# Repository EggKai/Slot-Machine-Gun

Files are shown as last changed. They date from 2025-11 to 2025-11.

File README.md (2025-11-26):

# Slot Machine Gun
This project serves as an allegory for the inherent risks of gambling, emphasizing how effortlessly individuals can descend a slippery slope of chance and compulsion through the personification and of these hazards in this playful, gamified form, combining a slot machine with a foam dart launcher and a face tracking gimbal.
Physical build

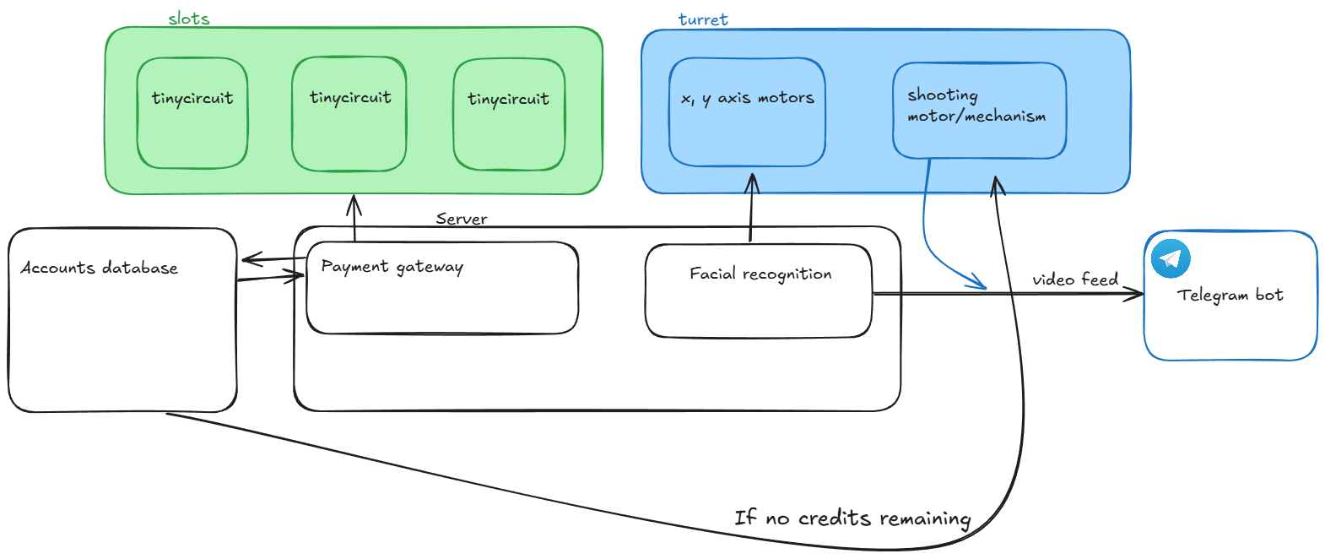
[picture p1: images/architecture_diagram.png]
System Architecture


## What's in the repo
- `slots/` - TinyScreen+ slot firmware (`jackpot_extra3x1.ino`) and MFRC522 RFID scan sketch (`rfid_scanner.ino`).
- `payment/gateway/` - Python bridge for RFID -> credit server and socket messaging to slots/turret.
- `payment/gateway/jackpot.py` - Slot "casino" server that drives the three slot displays and computes payouts.
- `payment/server/` - SQLite schema, forms, and stubs for the credit service that owns balances (plus Android NFC top-up client in `AppInterface/`).
- `turret/src/` - Arduino Uno firmware for three ULN2003/28BYJ-48 steppers (pan/tilt/fire) with a serial command set.
- `turret/host/` - Python tooling: serial CLI + OpenCV face tracking (`stepper_cli.py`) and Telegram clip sender (`killcambot.py`).
- `schematics/` and `images/` - Mechanical/electrical references, turret photos, and wiring diagrams.

## System design
- **Slots subsystem** - Three TinyScreen+ displays (clients 2, 3, 4) each with a WiFi TinyShield. They spin symbols and report results back to the jackpot server; they also render credit depletion and payout notices.
- **Payment gateway** - An MFRC522 RFID reader + Arduino serial output. A Python bridge charges spins against a credit service and forwards results to the jackpot server; it also notifies the turret when credits hit zero.
- **Credit service** - SQLite-backed HTTP API (expected to be served via `uvicorn main:app`). Holds RFID -> credit balances, admin UI, and Android NFC top-up app.
- **Turret** - Two-axis gear-driven rig plus a firing servo, controlled by Arduino firmware over serial. A host Python CLI performs face tracking and reacts to "NO CREDS" events via TCP.

### Key images
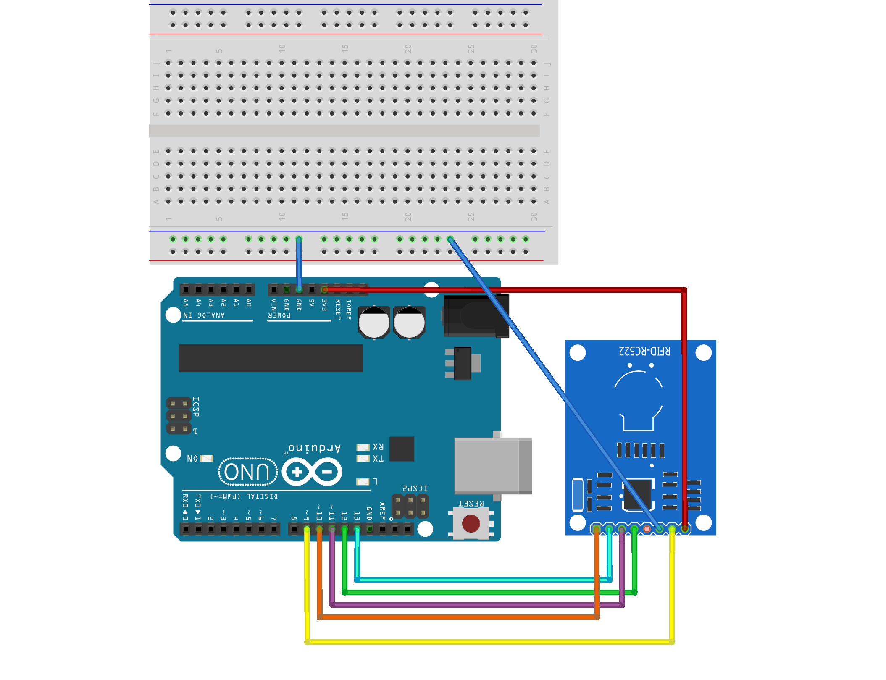
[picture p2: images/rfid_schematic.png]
RFID schematic
- Slots + payment wiring: 
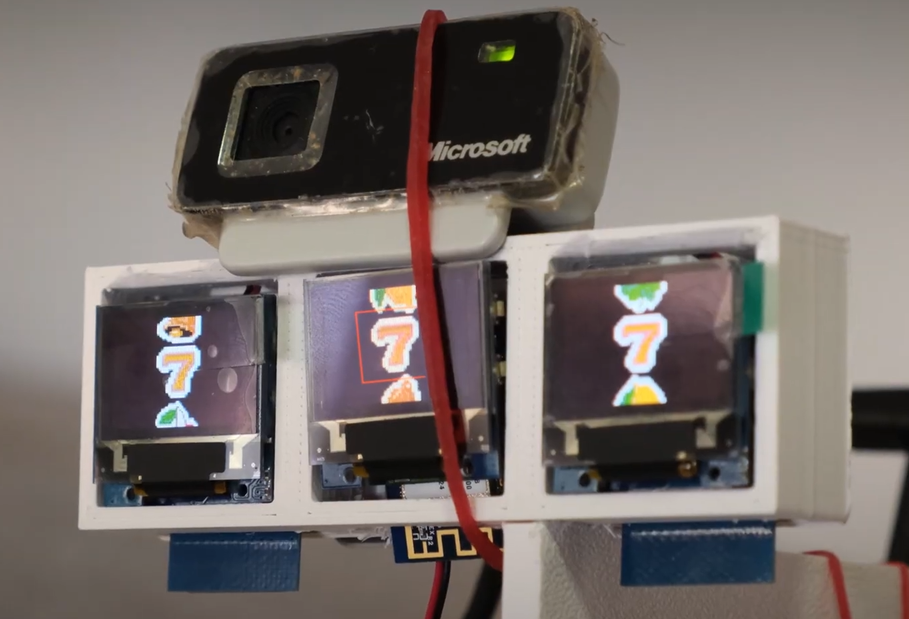
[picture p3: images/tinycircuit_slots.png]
TinyCircuits slots
- Slots UI: 
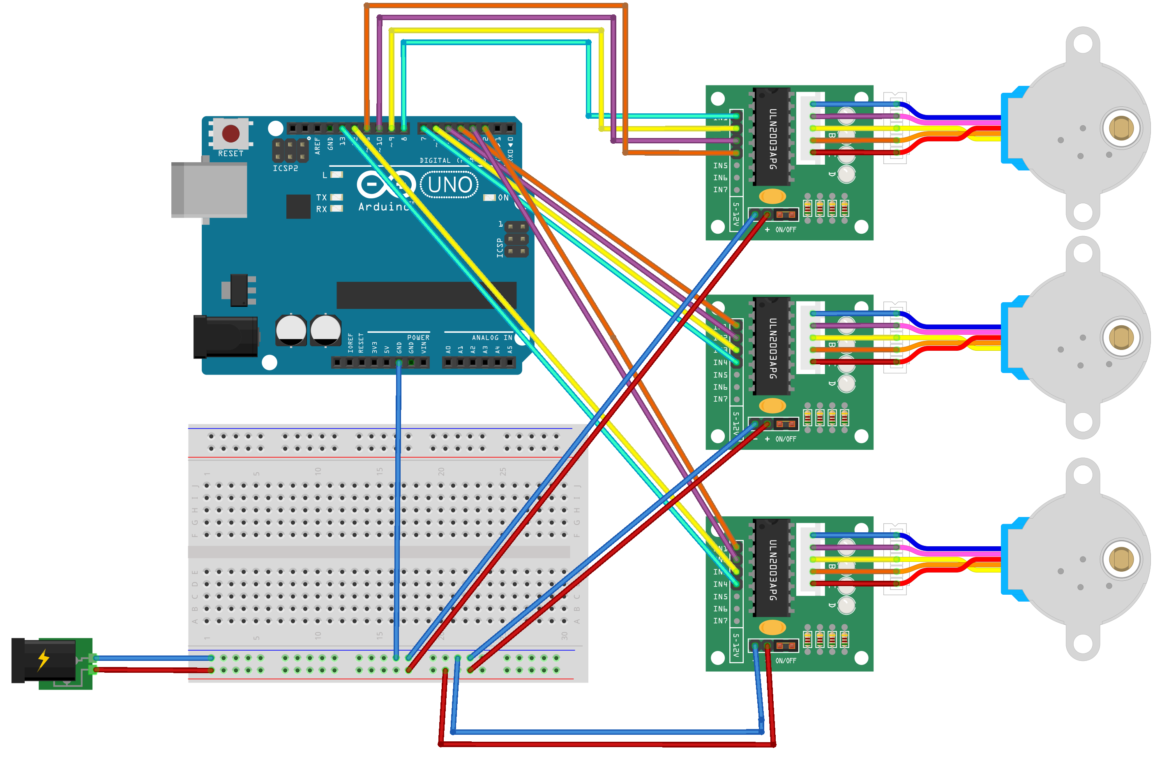
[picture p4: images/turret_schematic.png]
Turret schematic
- Turret wiring: 
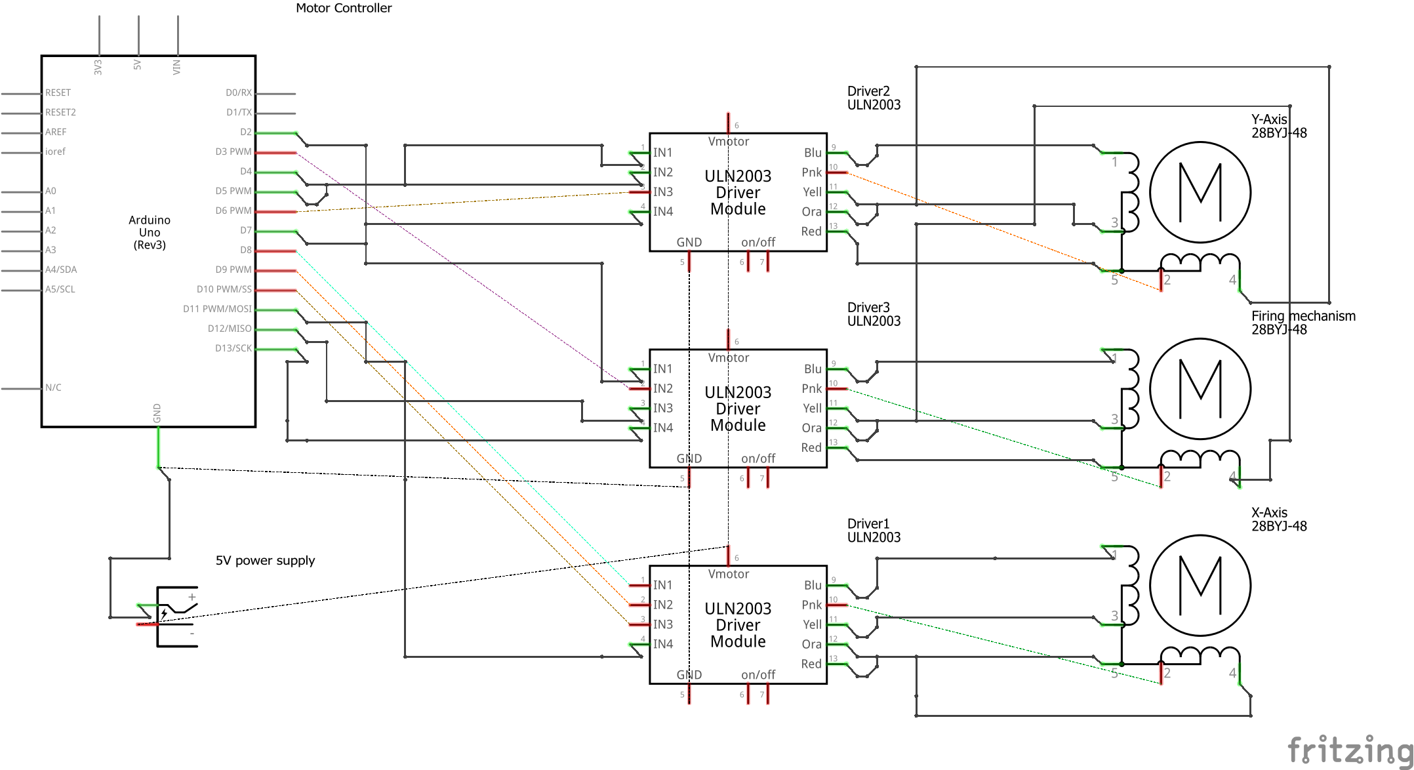
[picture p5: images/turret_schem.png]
Turret electrical wiring
- Turret wiring schema: 

## Parts lists
**Turret**

Components  
| Label | Part Type | mn | mpn | part number |
| --- | --- | --- | --- | --- |
| 5V power supply | Power plug |  |  |  |
| Driver1 | 28BYJ-48 Driver Module |  |  | ULN2003 |
| Driver2 | 28BYJ-48 Driver Module |  |  | ULN2003 |
| Driver3 | 28BYJ-48 Driver Module |  |  | ULN2003 |
| Firing mechanism | 28BYJ-48 Stepper Motor |  |  | 28BYJ-48 |
| Motor Controller | Arduino Uno (Rev3) |  |  |  |
| X-Axis | 28BYJ-48 Stepper Motor |  |  | 28BYJ-48 |
| Y-Axis | 28BYJ-48 Stepper Motor |  |  | 28BYJ-48 |

Quantities  
| Amount | Part Type | mn | mpn | part number |
| --- | --- | --- | --- | --- |
| 3 | 28BYJ-48 Driver Module |  |  | ULN2003 |
| 3 | 28BYJ-48 Stepper Motor |  |  | 28BYJ-48 |
| 1 | Arduino Uno (Rev3) |  |  |  |
| 1 | Power plug |  |  |  |

**Payment gateway**

Components  
| Label | Part Type | mn | mpn | part number |
| --- | --- | --- | --- | --- |
| Part1 | Arduino Uno (Rev3) |  |  |  |
| Part3 | RFID-RC522-v2 |  |  |  |

Quantities  
| Amount | Part Type | mn | mpn | part number |
| --- | --- | --- | --- | --- |
| 1 | Arduino Uno (Rev3) |  |  |  |
| 1 | RFID-RC522-v2 |  |  |  |

## Slots firmware (`slots/jackpot_extra3x1.ino`)
- Targets Arduino TinyScreen+ with WiFi TinyShield; draws three clipped symbol rows and performs weighted spins (`symbolOdds`).
- Networking: set `ssid`, `pass`, `serverIP`, and `port` (default `10.102.150.117:5000`). Each client sets a unique `devNum` (2, 3, or 4) and static IP (`localIp`).
- Protocol:
  - Client connects and sends `[0xFD, devNum]`. Server replies `0xFE` handshake; client answers `0xFF`.
  - A single byte `0-5` commands the middle symbol target; client streams 4 bytes back `[devNum, top, mid, bottom]`.
  - `0xAA` -> display "No Credits Left"; `0xAB` + payout byte -> show "You win N credits!".
  - High-bit masks (`0x80 | bits`) flash winning rows.
- Build/upload: use Arduino IDE with TinyScreen/WiFi101 libs, or PlatformIO if you port the board definition. Flash three devices with distinct `devNum`.
- For graphics, assets, and deeper slot behavior docs, see `slots/game_and_graphics_docs.pdf`.

## RFID scan sketch (`slots/rfid_scanner.ino`)
- MFRC522 wired to SS=D10, RST=D9; streams detected UID over serial to the Python gateway.
- Blocks further scans until it receives `DONE` (or `BAL:<float>`) over serial from the gateway.

## Jackpot server (`payment/gateway/jackpot.py`)
- Listens on `0.0.0.0:5000` for slot clients.
- Maintains credits, issues spin targets, collects results, computes payouts (`MULTIPLIERS`), and triggers row flashes.
- Commands:
  - Enter to roll random (deducts `BET`), `t N` to force all reels to symbol `N`.
  - `c` add 100 credits, `s` show credits, `set N` override balance, `q` quit.
- Also hosts a localhost-only channel for the RFID gateway: receives `"SUCCESS"` to roll and return a payout to the gateway, or `"NO CREDS"` to send `0xAA` to slots.

Run:
```bash
python payment/gateway/jackpot.py
```

## Payment gateway bridge (`payment/gateway/deduct_credits_to_spin.py`)
- Dependencies: `requests`, `pyserial`.
- Serial: listens to RFID UID lines from the Arduino on `SERIAL_PORT`/`BAUD_RATE`.
- HTTP: posts to credit API (`BASE_URL` deduct, `BASE_URL_2` add payout).
- Sockets:
  - Connects to jackpot server at `HOST:PORT` (default `127.0.0.1:5000`) to send `"SUCCESS"`/`"NO CREDS"` and read payout bytes.
  - Connects to turret listener at `HOST2:PORT2` (default `10.102.150.134:9000`) to forward `"NO CREDS"` so the turret can react.
- Serial flow: after each scan it sends `DONE` back to the Arduino to re-arm scanning.
- Update the hard-coded IPs/ports and amounts before running.

Run:
```bash
python payment/gateway/deduct_credits_to_spin.py
```

## Credit service (`payment/server`)
- SQLite schema in `database.py` with `users`, `rfid_cards`, and `customers`; DB file `shop.db`.
- Pydantic models in `models.py`; `.env` holds `DEDUCTION_AMOUNT`.
- Templates: login/register flows and `dashboard.html` for admin credit adjustments and customer listing.
- QA helper: `qa_test.py` posts a sample RFID deduct request to `http://127.0.0.1:8000/rfid/deduct`.
- Intended to run with `uvicorn main:app --reload --host <ip>` (see `start.txt`). Ensure `main.py` exposes a FastAPI/Starlette `app` and routes for:
  - `POST /rfid/deduct` and `POST /rfid/add` (used by the gateway bridge),
  - `POST /admin/add` (used by the Android NFC client),
  - auth + dashboard routes rendered from `templates/`.

> Note: the current `main.py` is a stub; wire up the FastAPI/Flask app to match the expected endpoints above.

## Android NFC top-up (`payment/server/AppInterface`)
- Simple NFC Activity (`MainActivity.kt`) reads a tag, displays the UID, and POSTs to `http://103.213.247.25:8000/admin/add` with `rfid_id` + `amount`.
- Built with Gradle/Kotlin (see `build.gradle.kts`); UI layout in `app/src/main/res/layout/activity_main.xml`.

## Turret firmware (`turret/src/main.cpp`)
- PlatformIO project for Arduino Uno driving three ULN2003/28BYJ-48 steppers (A: D8-D11, B: D4-D7, C: D2/D3/D12/D13) with direction inversion flags.
- Serial command set (115200 baud): `HELP`, `SPEED <rpm>`, `A|B|C <steps>`, `AB <a> <b>`, `ABC <a> <b> <c>`, `TARGET`, `STOP/RESUME`, `RELEASE`, `DEMO ON|OFF`.
- `TARGET` macro sweeps motor C; `DEMO` oscillates all axes for burn-in.
- Build/upload with PlatformIO:
```bash
cd turret
pio run -t upload
pio device monitor -b 115200
```

## Turret host tools (`turret/host`)
- `stepper_cli.py` - Serial client plus extras. With no arguments it now auto-runs face tracking + listener with: `track --port COM5 --cam 0 --cam-api dshow --rpm 12 --step-scale 0.05 --max-step 50 --listen-while-track (default on) --tcp-host 0.0.0.0 --tcp-port 9000`.
  - Basic commands: `python stepper_cli.py speed 15 --port COM5`.
  - Face tracking (custom): `python stepper_cli.py track --port COM5 --cam 0 --cam-api dshow --rpm 12 --step-scale 0.05 --max-step 50`.
  - TCP listener: `python stepper_cli.py listen --tcp-port 9000` to react to `"NO CREDS"` from the payment gateway (fires motor C sweep and optional camera clip).
  - Combined tracking + listener (custom ports/backends): `python stepper_cli.py track --listen-while-track (default on) --tcp-host 0.0.0.0 --tcp-port 9000`.
- `killcambot.py` - Utility to send recorded clips to Telegram subscribers; requires `python-telegram-bot` and a valid bot token/chat IDs.

## Suggested bring-up order
1. **Credit service** - Ensure `/rfid/deduct`, `/rfid/add`, and `/admin/add` endpoints work against `shop.db`.
2. **Jackpot server** - Start `payment/gateway/jackpot.py` and seed credits via the console (`c` or `set N`).
3. **Turret listener** - Run `stepper_cli.py listen --tcp-port 9000` (or `track --listen-while-track (default on)`).
4. **Gateway bridge** - Start `deduct_credits_to_spin.py` with correct serial port and API IPs.
5. **RFID scanner** - Flash `slots/rfid_scanner.ino` to the reader Arduino.
6. **Slot displays** - Flash `slots/jackpot_extra3x1.ino` to three TinyScreen+ units with `devNum` 2/3/4 and confirm they reach the server.

## Security & safety notes
- Secrets are currently in-source (WiFi SSID/password, Telegram bot token, service IPs). Rotate these for any real deployment.
- The build involves moving hardware (turret servos/steppers) and projectile firing-keep clearances, test without darts first, and add hard stops or current limits as needed.
- Gambling theme is illustrative only; do not deploy in environments with minors or where gambling content is restricted.

## Troubleshooting
- Slots not connecting: verify WiFi credentials, static IPs, and that `serverIP`/port are reachable; confirm the `0xFE/0xFF` handshake completes.
- No payouts: check jackpot console logs for missing device reports or insufficient credits; ensure `LINES` covers the row you expect.
- Gateway timeouts: confirm the credit API is reachable; inspect `BASE_URL`/`BASE_URL_2` and network paths.
- Turret not moving: check COM port, 5V supply to ULN2003 boards, and use `stepper_cli.py help` or `repl` to issue manual steps.

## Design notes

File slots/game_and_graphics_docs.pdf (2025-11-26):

# Gambling-Like Machine Using TinyCircuits and a Python Backend

Author: Tan Yehan

Date: 25/11/2025

## 1. Introduction

This report documents the design, implementation, and limitations of a gamblingmachine-like system constructed using three TinyCircuits boards (one TinyScreen+ and two TinyScreen units) equipped with WiFi TinyShields, acting as the slot-machine reels. The system communicates with a Python server that interprets results, enforces winning conditions, and issues commands back to the devices. Devices and Python server need to share the same Wifi AP.
The implementation served as part of a larger group project. This report covers only the components I directly developed and contributed, excluding architectural changes introduced later by teammates (e.g., DHCP support, credit display logic, or integration with an RFID-based credit and turret subsystem).

## 2. Hardware Overview

The system consists of:
- 3 TinyCircuits microcontroller units, each attached to
- one TinyScreen(+) display or TinyScreen(default) display,
- one WiFi TinyShield capable of basic TCP communication. Each device is programmed individually via the Arduino IDE using a dedicated .ino sketch.
All graphical assets (six slot icons) are stored as bitmaps:
- Bell
- Cherry
- Clover
- Diamond
- Lemon

- Seven
These are indexed 0–5 respectively on the microcontroller.

## 3. Software Architecture (Device Side)

## 3.1 Hardcoded Network Configuration

In the version I authored, each device contains:
- a hardcoded SSID and WiFi password,
- a fixed local IP address,
- the hardcoded IP address of the backend server.
This static addressing was required at the time because:
1. The device software must know the server IP before initiating the TCP handshake.
2. The backend required identifying devices by a predetermined “device number” (devNum).
3. Initially, each device’s identity was implicitly mapped to its IP address. Teammates later reworked this into a DHCP-compatible model. I do not document those changes here as they were not part of my contribution.

## 3.2 Device Identity (devNum)

Each TinyCircuit device sends a two-byte header upon connection:
[0xFD, devNum]
Only device numbers 2, 3, and 4 are valid.
These map to slot-machine columns 0, 1, and 2 respectively. Changes will need to be made for more device numbers and columns.

## 3.3 Local Odds and Symbol Selection

Each device maintains its own probability distribution for selecting the three row symbols during a spin. The odds I implemented were:

Symbol | Weight
Bell | 23

Symbol | Weight
Cherry | 23
Clover | 16

Diamond 16

Lemon | 13
Seven | 9

These weights apply only to the top and bottom rows after the design was scaled down (see Section 6).
The middle row is always assigned by the server, not by the device.

## 4. Server–Device Communication Protocol

## 4.1 Server Handshake and Heartbeat

After accepting a connection, the server expects:
Byte 0: 0xFD
Byte 1: devNum
If this header fails validation, the server drops the connection.
To check on the connection between device and server, the server periodically sends a handshake / keep-alive byte:
0xFE
If the client does not respond (e.g., due to crash or network loss), the server removes it from the active client list and waits for a new connection.

## 4.2 Commanding the Middle Row

To control the displayed result for the middle row, the server sends exactly one byte: 0–5 (index of symbol to display in middle row)
This allows the server to:
- randomly determine outcomes,

- enforce specific outcomes for testing or demonstration (e.g., guaranteed win/loss),
- synchronise the “middle row” across devices.
This design choice mimics real-world gambling systems where top/bottom rows often simulate randomness but have no effect on payout.

## 4.3 Device → Server Result Reporting

After each spin, the device sends four bytes:
[devNum, top, mid, bottom]
Each value is a symbol index (0–5).
The server aggregates these from all three devices to construct a 3×3 grid.

## 5. Backend (Python) Implementation Summary

The backend code, jackpot.py, contains:
- multithreaded TCP handlers,
- a central state table of connected clients,
- a shared results buffer,
- payout calculation logic,
- credit management (not part of my contribution),
- winning-line evaluation.

## 5.1 Winning-Line Limitation

Although the backend originally supported multiple winning lines:
- horizontal rows,
- vertical columns,
- diagonals,
my implementation restricted the win condition only to the middle row. Final used rule: [(1,0), (1,1), (1,2)]
In this scenario, a win occurs only if the three middle-row symbols match.

## 6. Flashing Winning Symbols

When a win is detected, the server sends a “flash mask” to each device. The relevant function is:
mask = 0b10000000 | (row_bits)
Where:
- bit 0 = flash top row
- bit 1 = flash middle row
- bit 2 = flash bottom row
- bit 7 = distinguishing flag (ensures byte ≥ 128 and cannot be confused with values 0–5)
Important limitation:
Only the middle row flashing is reliable.
The TinyScreen drawing code was originally written for a 3×3 slot machine, but midproject the system was reduced to a 3×1 machine.
The flashing routine for top/bottom rows references out-of-bounds image positions and therefore does not update the display correctly.
I did not have time to redo the rendering logic to match the new 3×1 design.

## 7. Architectural Limitations and Failure Points

As a critical self-evaluation (important for academic marking):

## 7.1 Hardcoded Network Parameters

- Static IP assignment is inflexible, fragile, and unsuitable for real-world deployment.
- A single mistyped IP leads to silent failure.
- No attempt is made to validate server reachability or recover gracefully.

## 7.2 Absence of Security

The system uses:
- no encryption,
- no authentication other than 0xFD header,
- no replay protection,

- no rate-limiting.
Any attacker on the same network can spoof devices or manipulate payouts.

## 7.3 Blocking I/O and Thread-per-Client Design

- Threads block indefinitely on socket reads.
- No timeout or cancellation is implemented for the main report loop.
- Thread-per-client model scales poorly beyond three devices.

## 7.4 Poor Error Handling on Device Side

- No retries on WiFi connection failure.
- No fallback server.
- No persistent storage of credits or machine state.
- Device reboots may desynchronise the game.

## 7.5 Rendering Logic Partially Broken

As noted earlier, flashing for top/bottom rows does not work due to outdated drawing logic.

## 7.6 Lack of Synchronisation During Animation

Device-side animations are not guaranteed to finish simultaneously.
This creates visual misalignment—undesirable in multi-reel gambling systems.

## 8. Work Done by Teammates (Not My Contribution)

The following features were implemented by teammates and are excluded from assessment of my contribution:
- DHCP support (dynamic addressing)
- A more sophisticated backend integrating:
- a credit system,
- RFID input,
- a turret firing mechanism
- A device-side credit display routine after each spin
- UI improvements and other refactoring

I make no claim to these components.

## 9. Conclusion

This project demonstrates a functional—though simplified and limited—networked slot-machine system using TinyCircuits hardware.
My contribution includes:
- probability-weighted symbol selection on devices,
- device–server protocol design (including handshake and flashing mask),
- middle-row command system,
- core rendering logic for the TinyScreen,
- result transmission,
- core server-side functions for parsing results and evaluating wins.
While the system works for demonstration and filming, it contains multiple architectural shortcomings typical of a time-constrained student project. A productionquality redesign would require significantly stronger error handling, secure communication, robust rendering code, and a scalable backend architecture.
As of this report, the github repo is public:
https://github.com/XxHanpowerxX/tinygamba

## 10. Declaration

Chatgpt usage is heavy among the coding (both server and client) and writing of this report. However, it cannot and could not be trusted blindly, especially for the coding. Due to varying versions of Arduino devices and the lack of projects made using Tinycircuit available to the AI model, it struggled heavily to answer many questions or gave completely false answers.
It is important to double check using the Tinycircuit devices and read up on documentation and examples for proper answers.

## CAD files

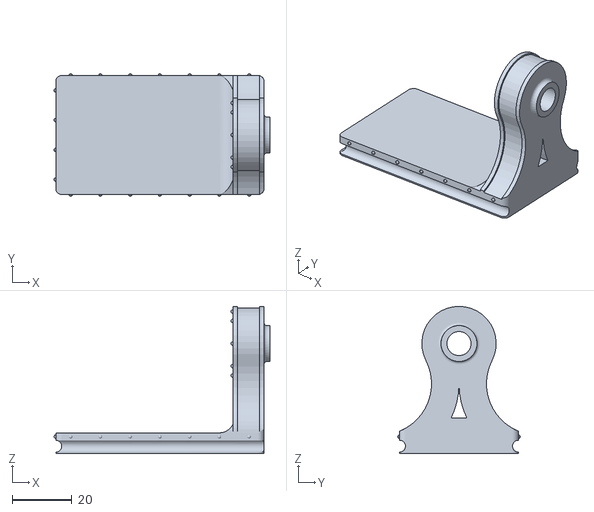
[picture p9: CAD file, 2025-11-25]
schematics/XYaxis/Tilt-full.STL
72.6 x 41.2 x 49.5

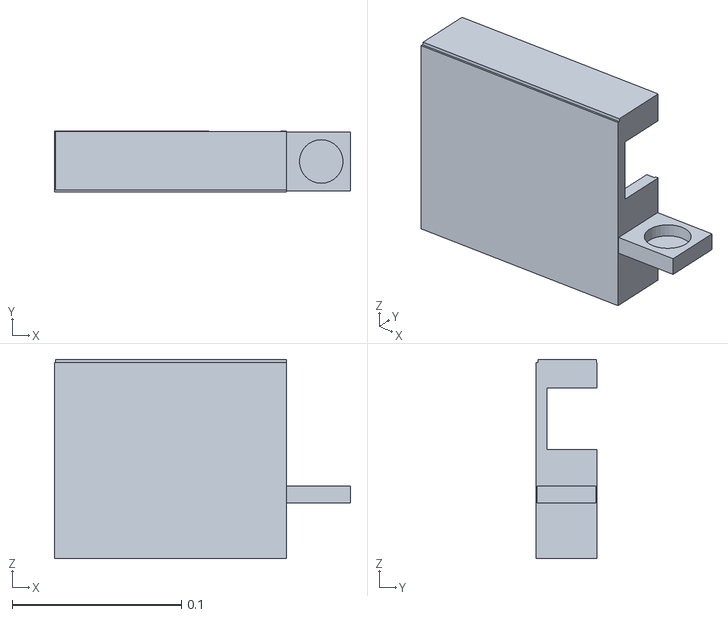
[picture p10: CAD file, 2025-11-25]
schematics/chassis/GunCasestl.stl
0.175 x 0.0359 x 0.118

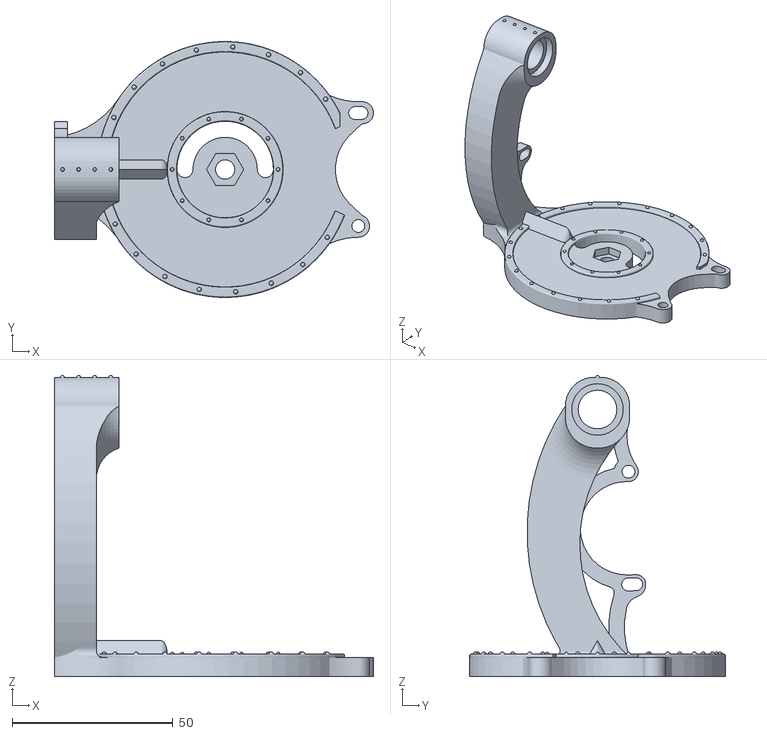
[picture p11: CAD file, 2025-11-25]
schematics/XYaxis/Pano.STL
99.1 x 79.5 x 93.6

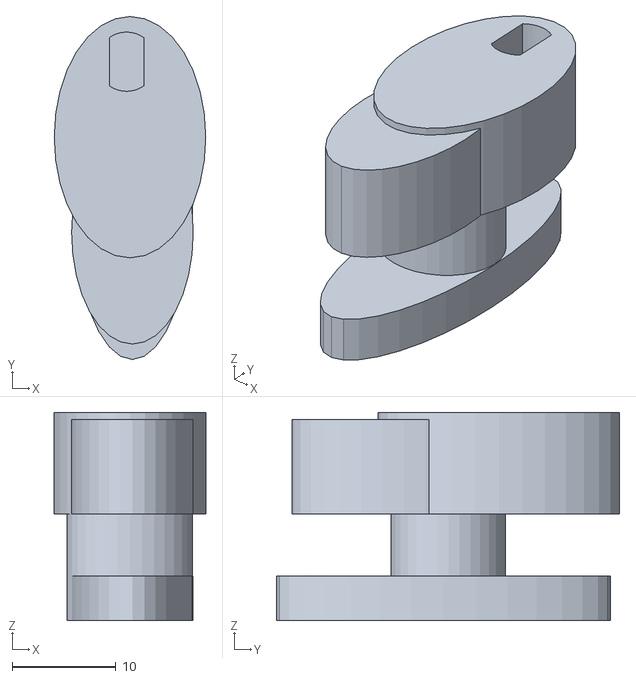
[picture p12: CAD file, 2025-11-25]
schematics/chassis/TinyCircuitHolder.stl
14.6 x 33.1 x 20.1

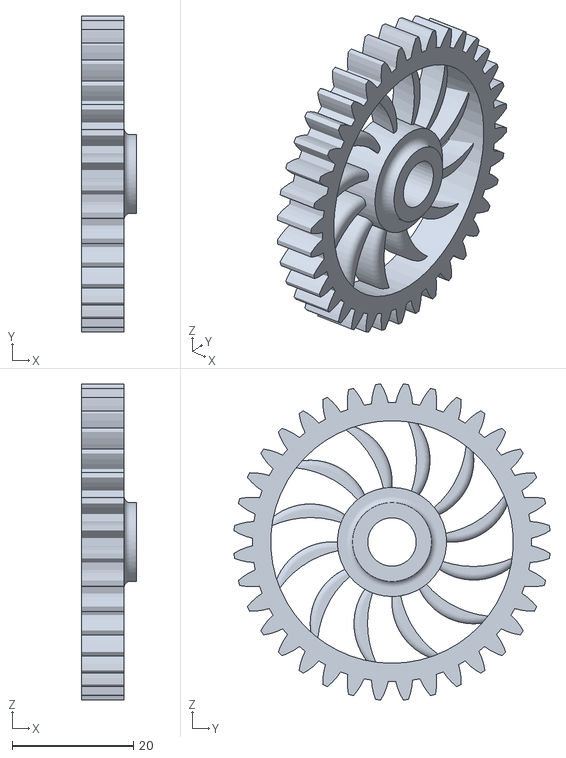
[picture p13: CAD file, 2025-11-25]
schematics/XYaxis/36T.STL
9.00 x 52.1 x 52.1

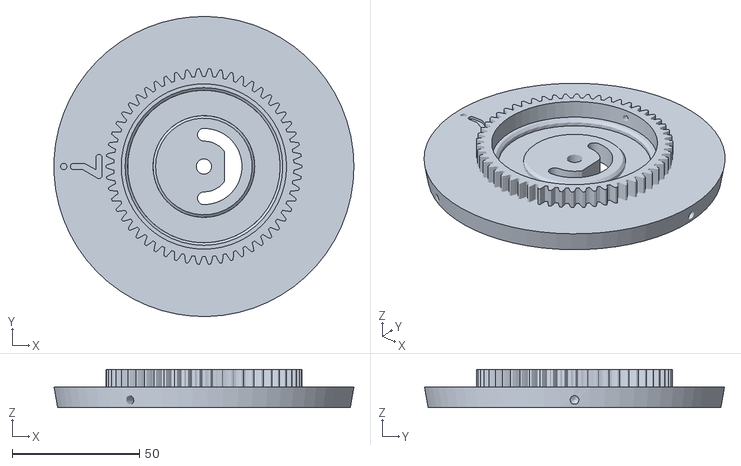
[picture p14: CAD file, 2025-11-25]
schematics/XYaxis/TopBase.STL
117.9 x 118.0 x 15.0

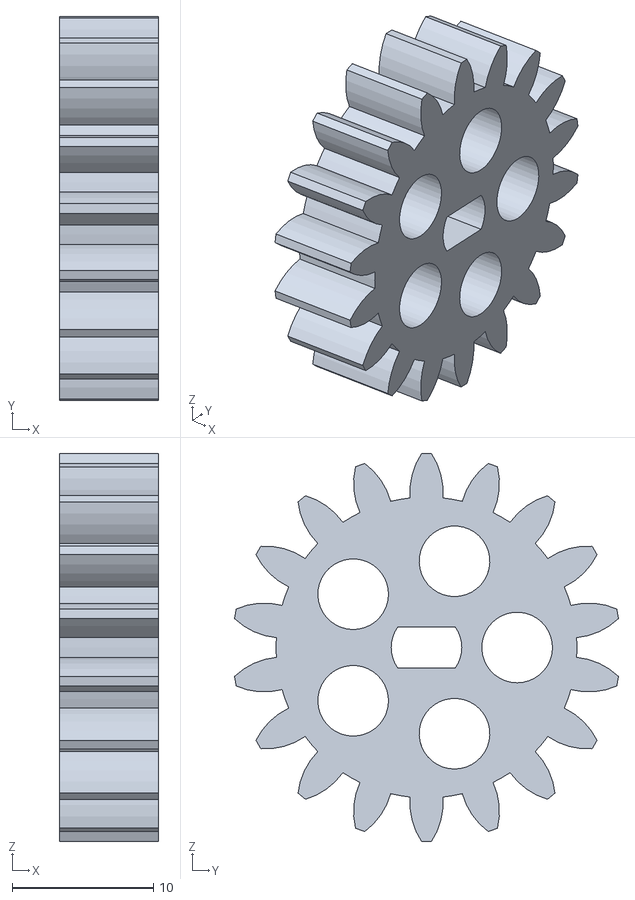
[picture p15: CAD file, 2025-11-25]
schematics/XYaxis/18T-Pan.STL
7.00 x 27.2 x 27.5

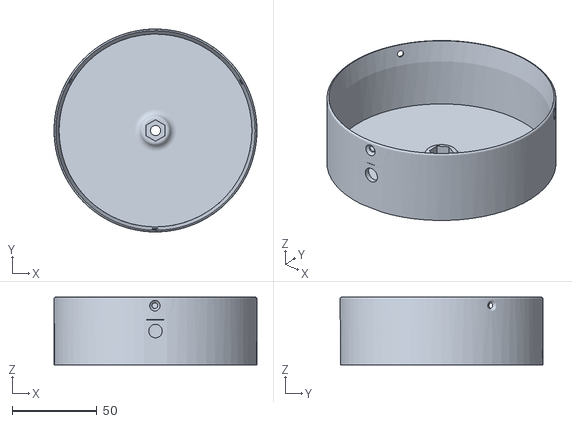
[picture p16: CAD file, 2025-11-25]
schematics/XYaxis/Socle.STL
120.0 x 120.0 x 40.0

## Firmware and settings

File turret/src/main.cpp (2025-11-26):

ca#include <Arduino.h>
#include <Stepper.h>

const int STEPS_PER_REV = 2048; // 28BYJ-48 typical

// Motor A wiring: IN1=D8, IN2=D9, IN3=D10, IN4=D11
// NOTE: Stepper constructor pin order is (IN1, IN3, IN2, IN4)
static const uint8_t A_IN1 = 8;
static const uint8_t A_IN2 = 9;
static const uint8_t A_IN3 = 10;
static const uint8_t A_IN4 = 11;
static const int A_DIR = -1; // invert A direction to match wiring
Stepper stepperA(STEPS_PER_REV, A_IN1, A_IN3, A_IN2, A_IN4);

// Motor B wiring: IN1=D4, IN2=D5, IN3=D6, IN4=D7
// NOTE: pass as (IN1, IN3, IN2, IN4)
static const uint8_t B_IN1 = 4;
static const uint8_t B_IN2 = 5;
static const uint8_t B_IN3 = 6;
static const uint8_t B_IN4 = 7;
static const int B_DIR = 1;
Stepper stepperB(STEPS_PER_REV, B_IN1, B_IN3, B_IN2, B_IN4);

// Motor C wiring: IN1=D2, IN2=D3, IN3=D12, IN4=D13
// NOTE: pass as (IN1, IN3, IN2, IN4)
static const uint8_t C_IN1 = 2;
static const uint8_t C_IN2 = 3;
static const uint8_t C_IN3 = 12;
static const uint8_t C_IN4 = 13;
static const int C_DIR = 1;
Stepper stepperC(STEPS_PER_REV, C_IN1, C_IN3, C_IN2, C_IN4);

// Runtime control
static bool enabled = true;       // 'S' to stop, 'R' to resume
static bool demo_mode = false;    // 'DEMO ON/OFF'

// De-energize the coils to stop holding torque and heat
void releaseCoils() {
  digitalWrite(A_IN1, LOW);
  digitalWrite(A_IN2, LOW);
  digitalWrite(A_IN3, LOW);
  digitalWrite(A_IN4, LOW);
  digitalWrite(B_IN1, LOW);
  digitalWrite(B_IN2, LOW);
  digitalWrite(B_IN3, LOW);
  digitalWrite(B_IN4, LOW);
  digitalWrite(C_IN1, LOW);
  digitalWrite(C_IN2, LOW);
  digitalWrite(C_IN3, LOW);
  digitalWrite(C_IN4, LOW);
}

// Step one motor with stop check
void stepMotor(Stepper &m, long steps) {
  int dir = (steps >= 0) ? 1 : -1;
  long count = steps >= 0 ? steps : -steps;
  for (long i = 0; i < count; ++i) {
    if (!enabled) { releaseCoils(); return; }
    m.step(dir);
  }
}

// Step all motors together, optionally different counts
void stepAll(long stepsA, long stepsB, long stepsC) {
  long aStep = stepsA * A_DIR;
  long bStep = stepsB * B_DIR;
  long cStep = stepsC * C_DIR;
  long a = aStep >= 0 ? aStep : -aStep;
  long b = bStep >= 0 ? bStep : -bStep;
  long c = cStep >= 0 ? cStep : -cStep;
  int dirA = (aStep >= 0) ? 1 : -1;
  int dirB = (bStep >= 0) ? 1 : -1;
  int dirC = (cStep >= 0) ? 1 : -1;
  while (a > 0 || b > 0 || c > 0) {
    if (!enabled) { releaseCoils(); return; }
    if (a > 0) { stepperA.step(dirA); --a; }
    if (b > 0) { stepperB.step(dirB); --b; }
    if (c > 0) { stepperC.step(dirC); --c; }
  }
}

static void printHelp() {
  Serial.println(F("Commands:"));
  Serial.println(F(" HELP                - show this help"));
  Serial.println(F(" SPEED <rpm>         - set speed for all motors (RPM)"));
  Serial.println(F(" A <steps>           - step motor A by N steps"));
  Serial.println(F(" B <steps>           - step motor B by N steps"));
  Serial.println(F(" C <steps>           - step motor C by N steps"));
  Serial.println(F(" AB <a> <b>          - step A=a, B=b steps"));
  Serial.println(F(" ABC <a> <b> <c>     - step A=a, B=b, C=c steps"));
  Serial.println(F(" TARGET              - camera-aim macro: C-150, wait, C+150"));
  Serial.println(F(" S | STOP            - stop + release coils"));
  Serial.println(F(" R | RESUME          - resume motion"));
  Serial.println(F(" RELEASE             - release coils (no hold)"));
  Serial.println(F(" DEMO ON|OFF         - toggle demo sweep mode"));
}

static bool parseLong(const String &tok, long &out) {
  if (tok.length() == 0) return false;
  char buf[24]; tok.toCharArray(buf, sizeof(buf));
  char *endp = nullptr;
  long v = strtol(buf, &endp, 10);
  if (endp == buf) return false; // no digits
  out = v; return true;
}

void setup() {
  Serial.begin(115200);
  Serial.setTimeout(25);
  // Ensure pins are outputs so releaseCoils() works immediately
  pinMode(A_IN1, OUTPUT); pinMode(A_IN2, OUTPUT); pinMode(A_IN3, OUTPUT); pinMode(A_IN4, OUTPUT);
  pinMode(B_IN1, OUTPUT); pinMode(B_IN2, OUTPUT); pinMode(B_IN3, OUTPUT); pinMode(B_IN4, OUTPUT);
  pinMode(C_IN1, OUTPUT); pinMode(C_IN2, OUTPUT); pinMode(C_IN3, OUTPUT); pinMode(C_IN4, OUTPUT);
  stepperA.setSpeed(12); // RPM start low
  stepperB.setSpeed(12);
  stepperC.setSpeed(12);
  Serial.println(F("READY ULN2003 28BYJ-48 (A:D8-11, B:D4-7, C:D2,D3,D12,D13)"));
  printHelp();
}

void loop() {
  // Handle line-based serial commands
  if (Serial.available()) {
    String line = Serial.readStringUntil('\n');
    line.trim();
    if (line.length()) {
      int sp = line.indexOf(' ');
      String cmd = sp >= 0 ? line.substring(0, sp) : line;
      String rest = sp >= 0 ? line.substring(sp + 1) : String();
      cmd.toUpperCase();

      if (cmd == "HELP" || cmd == "H" || cmd == "?") {
        printHelp();
      } else if (cmd == "S" || cmd == "STOP") {
        enabled = false; releaseCoils(); Serial.println(F("OK STOP"));
      } else if (cmd == "R" || cmd == "RESUME") {
        enabled = true; Serial.println(F("OK RESUME"));
      } else if (cmd == "RELEASE") {
        releaseCoils(); Serial.println(F("OK RELEASE"));
      } else if (cmd == "SPEED") {
        long rpm; if (parseLong(rest, rpm) && rpm > 0) {
          stepperA.setSpeed((long)rpm); stepperB.setSpeed((long)rpm); stepperC.setSpeed((long)rpm);
          Serial.println(F("OK SPEED"));
        } else {
          Serial.println(F("ERR SPEED"));
        }
      } else if (cmd == "A") {
        long n; if (parseLong(rest, n)) { stepMotor(stepperA, n * A_DIR); Serial.println(F("OK A")); }
      else Serial.println(F("ERR A"));
      } else if (cmd == "B") {
        long n; if (parseLong(rest, n)) { stepMotor(stepperB, n * B_DIR); Serial.println(F("OK B")); }
      else Serial.println(F("ERR B"));
      } else if (cmd == "C") {
        long n; if (parseLong(rest, n)) { stepMotor(stepperC, n * C_DIR); Serial.println(F("OK C")); }
      else Serial.println(F("ERR C"));
      } else if (cmd == "AB") {
        rest.trim(); int sp2 = rest.indexOf(' ');
        if (sp2 >= 0) {
          String sA = rest.substring(0, sp2); String sB = rest.substring(sp2 + 1); sB.trim();
          long a, b; if (parseLong(sA, a) && parseLong(sB, b)) { stepAll(a, b, 0); Serial.println(F("OK AB")); }
          else Serial.println(F("ERR AB"));
        } else {
          Serial.println(F("ERR AB"));
        }
      } else if (cmd == "ABC") {
        rest.trim(); int sp1 = rest.indexOf(' '); int sp2 = sp1 >= 0 ? rest.indexOf(' ', sp1 + 1) : -1;
        if (sp1 >= 0 && sp2 >= 0) {
          String sA = rest.substring(0, sp1);
          String sB = rest.substring(sp1 + 1, sp2); sB.trim();
          String sC = rest.substring(sp2 + 1); sC.trim();
          long a, b, c; if (parseLong(sA, a) && parseLong(sB, b) && parseLong(sC, c)) { stepAll(a, b, c); Serial.println(F("OK ABC")); }
          else Serial.println(F("ERR ABC"));
        } else {
          Serial.println(F("ERR ABC"));
        }
      } else if (cmd == "DEMO") {
        rest.trim();
        if (rest.equalsIgnoreCase("ON") || rest == "1") { demo_mode = true; Serial.println(F("OK DEMO ON")); }
        else if (rest.equalsIgnoreCase("OFF") || rest == "0") { demo_mode = false; Serial.println(F("OK DEMO OFF")); }
        else { demo_mode = !demo_mode; Serial.println(demo_mode ? F("OK DEMO ON") : F("OK DEMO OFF")); }
      } else if (cmd == "TARGET") {
        if (!enabled) { Serial.println(F("ERR TARGET STOPPED")); }
        else {
          // Simple macro: sweep C back, pause, then return
          stepMotor(stepperC, -150);
          delay(1000);
          stepMotor(stepperC, 150);
          Serial.println(F("OK TARGET"));
        }
      } else {
        Serial.println(F("ERR UNKNOWN"));
      }
    }
  }

  if (!enabled) { delay(2); return; }

  if (demo_mode) {
    stepAll(STEPS_PER_REV, STEPS_PER_REV, STEPS_PER_REV);
    delay(250);
    stepAll(-STEPS_PER_REV, -STEPS_PER_REV, -STEPS_PER_REV);
    delay(250);
  } else {
    delay(5); // idle
  }
}

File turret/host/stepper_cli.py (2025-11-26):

import argparse
import os
import socket
import sys
import threading
import time
from datetime import datetime
from typing import Optional

from killcambot import send_video_to_subscribers  # local helper to push recorded clips

try:
    import cv2
except Exception:
    cv2 = None

try:
    import serial  # pyserial
except ImportError:  # pragma: no cover
    print("pyserial not installed. Install with: pip install pyserial", file=sys.stderr)
    sys.exit(1)


class StepperClient:
    def __init__(self, port: str = "COM5", baud: int = 115200, timeout: float = 10.0, verbose: bool = False):
        self.verbose = verbose
        self.timeout = timeout
        self._lock = threading.Lock()
        self.ser = serial.Serial(port=port, baudrate=baud, timeout=timeout, write_timeout=timeout)
        time.sleep(2.0)  # allow Uno reset
        self.ser.reset_input_buffer()
        t0 = time.time()
        while time.time() - t0 < 1.0:
            line = self.ser.readline().decode(errors="ignore").strip()
            if not line:
                break
            if self.verbose:
                print(f"< {line}")

    def close(self):
        try:
            self.ser.close()
        except Exception:
            pass

    def _send(self, line: str) -> str:
        with self._lock:
            if not line.endswith("\n"):
                line += "\n"
            if self.verbose:
                print(f"> {line.rstrip()}")
            self.ser.reset_input_buffer()
            self.ser.write(line.encode("ascii"))
            self.ser.flush()
            end = time.time() + self.timeout
            resp = ""
            while time.time() < end:
                r = self.ser.readline().decode(errors="ignore").strip()
                if not r:
                    continue
                if r.startswith("READY") or r.startswith("Commands:"):
                    continue
                resp = r
                break
            if self.verbose and resp:
                print(f"< {resp}")
            return resp

    # High-level helpers
    def help(self) -> str:
        self.ser.reset_input_buffer()
        self._send("HELP")
        lines = []
        t0 = time.time()
        while time.time() - t0 < 0.5:
            line = self.ser.readline().decode(errors="ignore").rstrip()
            if not line:
                break
            lines.append(line)
        return "\n".join(lines)

    def speed(self, rpm: int) -> str:
        return self._send(f"SPEED {rpm}")

    def stop(self) -> str:
        return self._send("STOP")

    def resume(self) -> str:
        return self._send("RESUME")

    def release(self) -> str:
        return self._send("RELEASE")

    def step_a(self, steps: int) -> str:
        return self._send(f"A {steps}")

    def step_b(self, steps: int) -> str:
        return self._send(f"B {steps}")

    def step_c(self, steps: int) -> str:
        return self._send(f"C {steps}")

    def step_ab(self, a_steps: int, b_steps: int) -> str:
        return self._send(f"AB {a_steps} {b_steps}")

    def step_abc(self, a_steps: int, b_steps: int, c_steps: int) -> str:
        return self._send(f"ABC {a_steps} {b_steps} {c_steps}")

    def target(self) -> str:
        return self._send("TARGET")

    def demo(self, on: Optional[bool] = None) -> str:
        if on is None:
            return self._send("DEMO")
        return self._send("DEMO ON" if on else "DEMO OFF")


def _track_face(ns, client: StepperClient):
    if cv2 is None:
        sys.exit("OpenCV not installed. Install with: pip install opencv-python")
    if ns.rpm and ns.rpm > 0:
        client.speed(int(ns.rpm))

    api_map = {
        "auto": getattr(cv2, "CAP_ANY", 0),
        "dshow": getattr(cv2, "CAP_DSHOW", 700),
        "msmf": getattr(cv2, "CAP_MSMF", 1400),
        "v4l2": getattr(cv2, "CAP_V4L2", 200),
        "avfoundation": getattr(cv2, "CAP_AVFOUNDATION", 1200),
        "gstreamer": getattr(cv2, "CAP_GSTREAMER", 1800),
    }
    cam_src = ns.cam
    try:
        cam_src = int(ns.cam)
    except ValueError:
        pass
    cap = cv2.VideoCapture(cam_src, api_map.get(ns.cam_api, api_map["auto"]))
    if not cap.isOpened():
        sys.exit(f"Failed to open camera {ns.cam} with api {ns.cam_api}")

    cascade_path = getattr(cv2.data, "haarcascades", None)
    face_model = cascade_path + "haarcascade_frontalface_default.xml" if cascade_path else None
    if not face_model:
        sys.exit("Could not locate haarcascade_frontalface_default.xml")
    face_cascade = cv2.CascadeClassifier(face_model)
    if face_cascade.empty():
        sys.exit("Failed to load Haar cascade")

    print("Tracking... press 'q' to quit")
    try:
        while True:
            ok, frame = cap.read()
            if not ok or frame is None:
                time.sleep(0.01)
                continue
            gray = cv2.cvtColor(frame, cv2.COLOR_BGR2GRAY)
            faces = face_cascade.detectMultiScale(
                gray, scaleFactor=1.2, minNeighbors=5, minSize=(ns.min_face, ns.min_face)
            )
            h, w = frame.shape[:2]
            cx_tgt, cy_tgt = w / 2.0, h / 2.0
            step_x = step_y = 0
            if len(faces) > 0:
                x, y, fw, fh = max(faces, key=lambda f: f[2] * f[3])
                cx = x + fw / 2.0
                cy = y + fh / 2.0
                err_x = cx - cx_tgt
                err_y = cy - cy_tgt
                step_x = int(max(-ns.max_step, min(ns.max_step, err_x * ns.step_scale)))
                step_y = int(max(-ns.max_step, min(ns.max_step, err_y * ns.step_scale)))
                if ns.invert_x:
                    step_x = -step_x
                if ns.invert_y:
                    step_y = -step_y
                if not ns.no_display:
                    cv2.rectangle(frame, (x, y), (x + fw, y + fh), (0, 255, 0), 2)
                    cv2.circle(frame, (int(cx), int(cy)), 4, (0, 0, 255), -1)
            if step_x != 0 or step_y != 0:
                client.step_ab(step_x, -step_y)  # negate Y so positive err_y drives up if wiring matches
            if not ns.no_display:
                cv2.drawMarker(frame, (int(cx_tgt), int(cy_tgt)), (255, 255, 0), cv2.MARKER_CROSS, 20, 2)
                cv2.putText(frame, f"err=({step_x},{step_y})", (10, 20), cv2.FONT_HERSHEY_SIMPLEX, 0.5,
                            (0, 255, 255), 1, cv2.LINE_AA)
                cv2.imshow("FaceTrack", frame)
                key = cv2.waitKey(1) & 0xFF
                if key == ord("q"):
                    break
            else:
                time.sleep(0.03)
    finally:
        try:
            cap.release()
        except Exception:
            pass
        if not ns.no_display:
            try:
                cv2.destroyAllWindows()
            except Exception:
                pass
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
